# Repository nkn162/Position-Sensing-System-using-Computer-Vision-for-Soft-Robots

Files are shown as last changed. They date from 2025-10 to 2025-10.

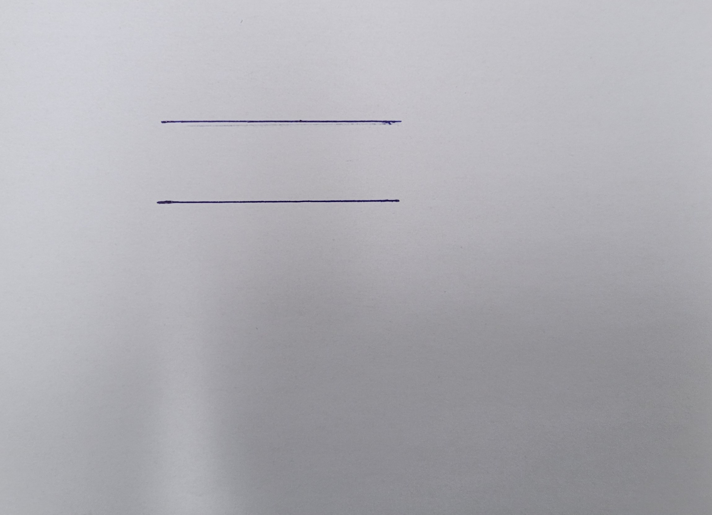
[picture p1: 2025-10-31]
Computer_Vision/Test_Inputs/image2.jpg

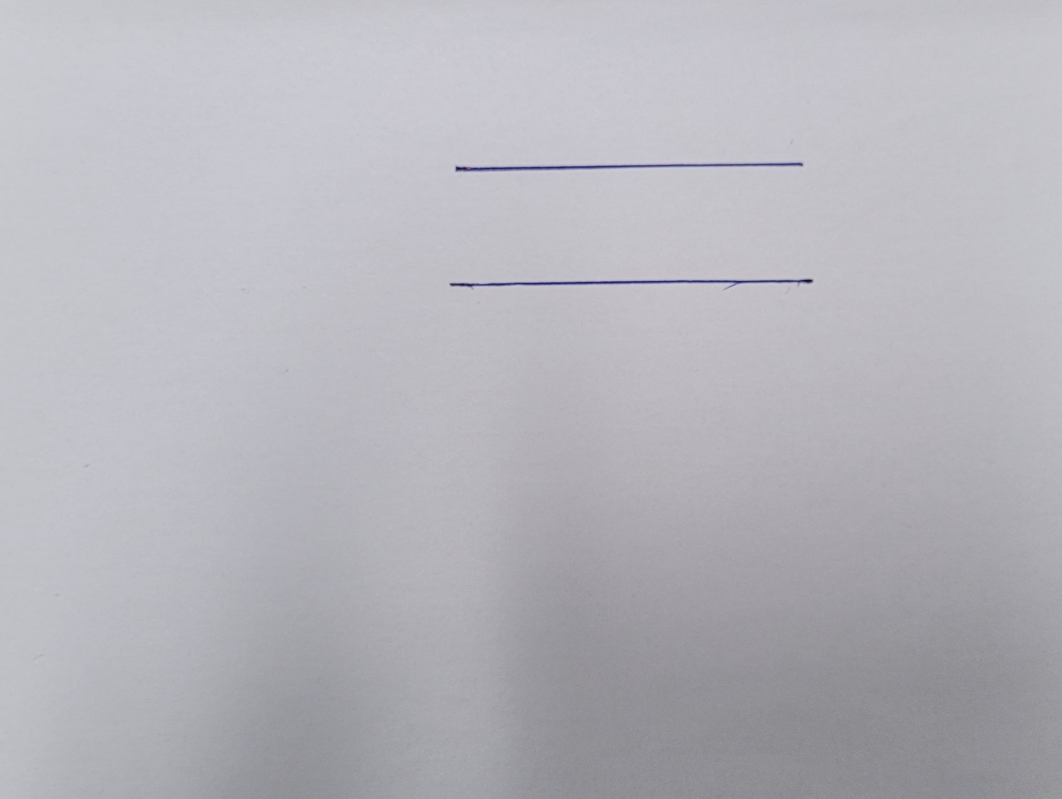
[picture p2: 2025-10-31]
Computer_Vision/Test_Inputs/image1.jpg

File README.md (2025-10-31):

# MRI-Safe Position Sensing for Soft Robotic Actuators via Computer Vision

## Master's Dissertation: A Novel Passive Sensing Approach for MIS

This Master's dissertation addresses a foundational challenge in future medical robotics: **accurate, flexible position sensing for soft actuators operating within the MRI environment.** Traditional sensing methods (EM/FBG sensors) introduce cost, complexity, or compromise the robot's essential compliance.

This project developed and validated a **novel, low-cost, and fully MRI-compatible passive mechanical sensing system** capable of inferring 3D tip position by tracking linear cable displacement using advanced Computer Vision techniques.

| Research Domain | Key Challenges Addressed | Core Technical Solution |
| :--- | :--- | :--- |
| **Computer Vision** | Real-time, sub-millimeter tracking of marked segments across low-contrast video streams. | Custom **Python/OpenCV** pipeline with temporal stability heuristics. |
| **Control & Kinematics** | Actuation control with NEMA 17 steppers; compensating for non-linearities and hysteresis inherent to soft actuators. | Calibrated **Constant Curvature Model (CCM)** firmware (Arduino). |
| **Medical Robotics** | MRI safety, preservation of soft actuator flexibility, low-cost disposal (single-use). | Passive cable displacement mechanism; non-metallic materials. |

---

## Contribution 1: Advanced Computer Vision Pipeline

The project implemented a sophisticated Computer Vision pipeline in **Python (OpenCV)**, optimised for real-time, accurate tracking of cable displacement at the actuator's proximal end.

### 1. Robust Detection & Filtering

The pipeline was engineered to reliably extract displacement data from high-noise, low-feature video frames - static images first before scaling towards video:
* **Pre-processing:** Utilised **CLAHE (Contrast Limited Adaptive Histogram Equalisation)** to locally enhance contrast, successfully resolving cable line visibility where simple global thresholding failed.
* **Feature Extraction:** Employed an adaptive **Canny Edge Detector** followed by a **Probabilistic Hough Transform** to parameterize the fragmented, near-horizontal cable lines.
* **Refinement:** Custom logic applied **Morphological Closing** to fuse broken segments and proximity-based merging to eliminate line duplicates resulting from cable thickness. *(See `Computer_Vision/edge_detection_5.py`)*

### 2. Temporal Tracking & Compensation

The system was scaled for dynamic video analysis, ensuring stability and compensation for physical artifacts during movement:
* **Stability:** **Persistence Logic** was implemented to reuse previous frame coordinates upon transient detection failure, ensuring a continuous and stable data stream at 30 FPS.
* **Motion Modeling:** To smooth inherent latency jumps in the raw coordinates, **Linear Interpolation** was applied to the displacement data between frames, accurately emulating the soft actuator's mechanical movement profile. *(See `Computer_Vision/Sensing_5.py`)*

---

## Contribution 2: Calibrated Kinematic Control Subsystem

To validate the sensing system, a controlled, cable-driven actuation platform was developed using an Arduino Due, integrating a corrected CCM (Constant Curavture Model) to handle the soft robot's mechanical non-linearities.

### 1. Actuator Control Firmware (`Actuator_Control/CCM_Trial_3.ino`)

The firmware implements the core kinematic logic for 3-DoF actuation via serial command (A, J, Z, R) on an **Arduino Due**:
* **Kinematics:** The **CCM** is used to calculate the necessary cable length change ($\Delta L$) for a target bending angle ($\psi$).
* **HMI:** Essential control commands (A: Absolute Move, J: Jog, Z: Zero Position) were implemented to facilitate manual compensation of mechanical slack and hysteresis during experimental resets.

### 2. Experimental Calibration and Correction

Physical trials revealed that the ideal CCM significantly overestimated bending. Analysis corrected the model for compliance, friction, and slack:
* **Correction Parameters:** Empirically derived parameters—**Actuation Efficiency ($\eta = 0.362$ scaling $\Delta L$)** and **Deadband ($\Delta L_0 = 3.04$ mm)**—were introduced and embedded in the firmware's logic to drastically improve prediction accuracy.
* **Hysteresis Analysis:** The experimental procedure included analysing hysteresis (measured up to $8.63^\circ$ at high deflection) and developing operational procedures (the 'Z' command) to mitigate its effect during validation runs.

---

## Contribution 3: Sensing Validation and Research Outcomes

The integrated system validated the viability of CV-based sensing, with quantified accuracy demonstrated through statistical modeling.

### 1. Non-Linear Mapping and Accuracy

* **Model Selection:** **Python regression analysis** was used to model the relationship between pixel displacement and bending angle. The **Quadratic Regression Model** was selected, yielding the lowest total error ($\text{RMSE} = 2.01^\circ$ across the full calibration set) due to its superior fit for the soft robot's intrinsic curvature. *(See `Calibration_Model/Correlation_Performance_2.py`)*
* **Final Accuracy:** The validated sensing system achieved high performance, with errors below **$\text{RMSE} = 0.81^\circ$** for typical surgical deflections ($> 15^\circ$).

### 2. Research Trajectory

This project establishes a strong foundation for advanced research by identifying the precise limitations and the pathway for a next-generation closed-loop control system:
* **Limitation:** Higher error observed at low angles ($\text{RMSE} \approx 3^\circ$), driven by minimal cable displacement visibility.
* **Proposed Solution:** The dissertation concludes that a design shift to **segmented PTFE tubes** would amplify displacement, directly addressing the low-angle sensitivity and paving the way for full-range high-accuracy position sensing. Furthermore, larger calibration data would provide a better fit for the correlation between measured displacement and bending angles. Trials using NDI Aurora Tracker, multi-camera environment, or evaluation against FBG sensors could validate the performance of the proposed sensing system more accurately and provide the pathway to further development of utilsing it for **closed-loop control integration**.

---

## Repository Structure

| Folder | Contents | Key Skills Highlighted |
| :--- | :--- | :--- |
| `Computer_Vision/Code_Files` | `edge_detection_5.py`, `Sensing_5.py` | **Python/OpenCV**, Image Processing (CLAHE, Canny), Temporal Tracking, Signal Processing. |
| `Computer_Vision/Code_Files` | `Correlation_Performance_2.py` | **Non-Linear Regression**, Data Analysis, Statistical Validation (RMSE). |
| `Control/` | `CCM_Trial_3.ino` | **Embedded C (Arduino)**, Stepper Motor Control, **Calibrated Kinematics**, HIL Prototyping. |
| `Output/` | Plots of calibration fit, residual analysis, and prototype schematics. | **Research Visualisation**. |

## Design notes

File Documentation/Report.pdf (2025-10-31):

## MRI Compatible Position Sensing for Soft Continuum Surgical Robots

MECH5845 Professional Project Author Name: Neeraj Krishnan Nambudiri
SID: 201887240
Supervisor Name: Dr. James Avery Examiner Name: Dr. George
Jackson-Mills
Date of Submission: 14/08/2025 MRI Compatible Position Sensing for Soft Continuum Surgical Robots

ii

SCHOOL OF MECHANICAL
ENGINEERING

MECH5840

TITLE OF PROJECT

PRESENTED BY

If The Project Is Industrially Linked Tick This Box And Provide Details Below

This project report presents my own work and does not contain any unacknowledged work from any other sources.

Signed | Date: 14/08/2025

Version 17, 2020-21

MECH5845M Professional Project

MRI Compatible Position Sensing for Soft Continuum Surgical Robots

Neeraj Krishnan Nambudiri

Company Name and Address:

INDUSTRIAL MENTOR:

iii

### Acknowledgements

I would like to express my deepest gratitude to my supervisor, Dr. James Avery, for

his continued guidance and support through the duration of this project. His advice

has been invaluable throughout the course and has made it possible for me to

achieve the project results.

I would also like to thank Sam Wilson for his guidance and cooperation in using the

lab space and equipment to conduct the project.

iv

### Table of Contents

v

vi

### Abstract

Minimally Invasive Surgery (MIS) increasingly employs soft continuum robots for their

dexterity, reduced-traumatic interaction, and ability to navigate complex anatomical

pathways. In procedures guided by Magnetic Resonance Imaging (MRI), sensing the

robot’s position is critical for accurate manipulation and safety. However, many

established tracking technologies face challenges of MRI incompatibility, size

constraints, or high cost.

This project presents the design and evaluation of an MRI-compatible, low-cost

sensing system for real-time curvature and tip position estimation in a cable-driven

soft continuum robot. The approach uses non-metallic tendons routed through PTFE

channels, with one end fixed at the robot tip and the other marked for visual detection

outside the MRI environment. A computer vision algorithm processes video frames to

track cable displacement, which is correlated to bending angle through calibration.

The development process included iterative refinement of image processing pipelines

from static to dynamic tracking, integration with a single-tendon cable-driven

actuation system based on the Constant Curvature Model (CCM), and calibration

using physical bending trials. Validation was conducted by comparing sensor-derived

angles with both manually measured angles and CCM predictions.

The system demonstrated reliable performance for moderate to large bends, meeting

real-time frame rate targets and maintaining MRI safety by keeping all sensing

electronics outside the scanner field. The results indicate that optical cable-

displacement tracking is a viable and scalable solution for MRI-guided continuum

robot sensing, with potential for integration into closed-loop surgical control systems.

vii

## Chapter 1

## Introduction

### 1.1 Background

Modern-day healthcare has been revolutionised by the introduction of Minimally

invasive surgery (MIS). It has enabled precision-driven procedures, aimed at

reducing patient trauma. In the applicable surgical domains, Robotic MIS has started

replacing open surgeries, due to its significant benefits such as greater patient safety,

faster recovery, lower post-operative problems, and reduced in-patient duration [1][2].

However, long and rigid instruments are used in traditional robot-assisted MIS, which

can have restrictions due to the fulcrum effect and some collateral damage to

surrounding tissue. This has resulted in prominent research developing soft robotics

for MIS, focused on combining rigid robotic control with flexibility and safety of soft

materials [2]. Figure 1.1 showcases the evolution of MIS and introduction of flexible

instruments in the field.

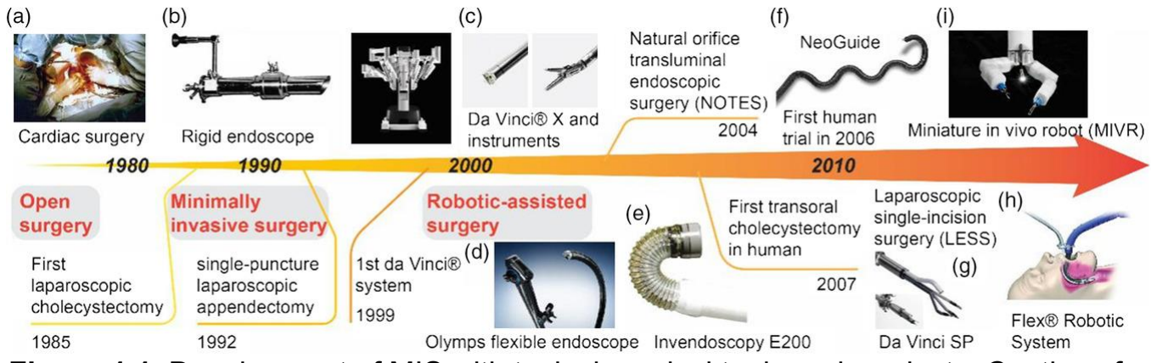
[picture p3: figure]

Figure 1.1: Development of MIS with typical surgical tools and products. Captions for individual images included within [3].

Simultaneously, the intervention of advanced imaging techniques, such as Computed

Tomography (CT), Ultrasound, X-ray, and Magnetic Resonance Imaging (MRI), with

MIS is also being developed. Among these, only MRI provides the data without any

ionising radiation. Hence, comprehensive study for integrating MRI during MIS

procedures is ongoing [4]. However, it poses considerable challenges due to the

presence of strong magnetic field, thus prohibiting the use of conventional metallic or

electrical sensing mechanisms for robotic control. Hence, development of alternative

proprioceptive sensing solutions is paramount. The most widely investigated sensing

technology is optical-based sensing, such as Fibre-Bragg Grating (FBG), fibre-scope,

and Fabry-Perot interferometer (FPI) [5]. They have exhibited high accuracy but also

have relatively higher stiffness which reduces the flexibility of the soft robotic manipulators and are very expensive, which limits their integration in single-use soft

surgical robots.

Accordingly, this project involves the design and evaluation of an MRI-compatible

sensing system tailored for the position tracking and motion control of a soft

continuum robot. It utilises a low-cost, flexible sensing system based on cable

transmission. The displacement of this cable, induced by robotic movement, is

captured using a camera setup and employing Computer Vision (CV) algorithm. It is

correlated to the bending angles for accurate position tracking, and its performance is

evaluated to analyse potential of offering a non-intrusive method for accurate motion

tracking without interference with MRI functionality. Figure 1.2 shows the reference

design of a soft-continuum robot.

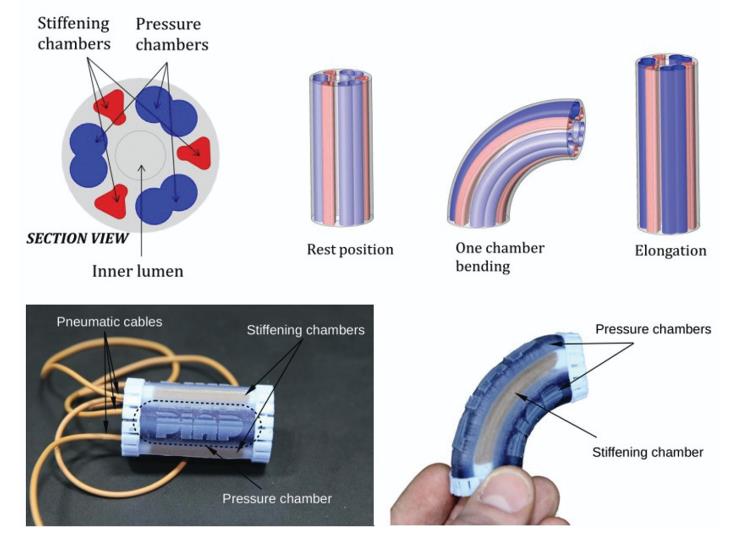
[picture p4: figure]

Figure 1.2: Example of a Soft Robot [6].

### 1.1 Project Aim

This project aims to develop and evaluate a size and stiffness tuneable, metal-free,

MRI-compatible sensing system for real-time position tracking of a soft continuum

surgical robot used in minimally invasive procedures.

### 1.2 Project Objectives

The key objectives to achieve the project aim are as follows:

1. Review relevant literature to understand the benefits and limitations of

existing technologies and finalise the methodology.

2. Design and implement the sensing system utilising Polytetrafluoroethylene

(PTFE) tubing and cable-displacement mechanism for motion tracking.

3. Integrate the sensor with the cable-driven continuum robot after preliminary

testing.

4. Develop a CV algorithm for detecting and quantifying edge displacement and

establish a robust correlation between detected cable-displacement and

robotic motion parameters.

5. Calibrate and perform validation to ensure system reliability, repeatability of

results, and account for hysteresis errors.

6. Assess accuracy, latency, speed, and precision of the proposed sensing

system.

7. Compare results with established sensing technologies such as Fiber-Bragg

Grating (FBG) and EM-tracker.

8. Target accuracy within 0.2 mm, delay of 0.1 seconds and frame rate of 30 fps.

### 1.3 Project Report Layout

- Chapter 1 – Introduction: Establishes the background of the project and

specifies the corresponding aims and objectives.

- Chapter 2 – Literature Review: Provides a critical review of relevant literature

for all aspects of the project, from MRI-guided MIS to Fabrication methods.

- Chapters 3 to 5 – Project Development: Describes in detail the methodologies

of all the aspects – CV system, Fabrication, and Actuation Control.

- Chapter 6 – Validation Experiment: Describes the experimental setup and

methodology for evaluation of the sensing system, along with the results and

analysis of its performance.

- Chapter 7 – Conclusion: Summarises the key achievements, results,

discusses significance and limitations of the findings, and outlines potential

pathways for future work.

## Chapter 2

## Literature Review

### 2.1 Introduction

The convergence of soft robotics and MRI-guided intervention in MIS procedures

have amplified the need for developing robust, accurate, and reliable soft sensing

technologies and unveils a new, critical frontier in the field of medical robotics

research. They are capable of navigating complex anatomical structures, providing

additional dexterity and accessibility [7]. The robotic systems also elevate the skills of

a surgeon, while delivering higher precision and accuracy [8]. At the same time, it

also presents interdisciplinary challenges, due to the multiple constraints – clinical

and technical. To overcome these challenges, adaptation and re-imagining of the

feedback mechanisms for robot position is required. This literature review will explore

the current benchmarks in the domain. Furthermore, validation of the proposed

sensing system requires the development of a working prototype of the soft

continuum robot, which is also discussed briefly.

### 2.2 MRI Guidance in Minimally Invasive Surgery

MRI stands as the benchmark for soft tissue visualisation and hence adds

considerable value when used as guiding intervention for MIS procedures. It offers

unparalleled contrast resolution, continuous and real-time monitoring without any

cumulative radiation exposure – critical for patient safety. But it also necessitates

specific surgical instrumentation, based on the constraints exemplified due to the

presence of strong magnetic fields in these environments.

2.2.1 Regulations for MRI Compatibility

The electromagnetic compatibility of components and devices used in a surgical

procedure are critical in an MRI environment. Based on their safety in MRI

environment, the American Society for Testing and Materials (ASTM) F2503 [9]

categorises the systems into three: MR Safe, MR Conditional, and MR Unsafe. MR

Safe devices are neither affected nor influence the magnetic field in an MRI

environment. These instruments are made of non-metallic, non-conductive, and non-

magnetic materials. MR Conditional stipulates instruments which are demonstrated

to be safe in an MRI environment, but only under specific conditions. MR Unsafe

devices are classified as hazardous for functioning in an MRI environment [9].

Based on this classification by ASTM, this project aims at developing the sensing

system which would be MR Safe, thus highlighting its application in all MRI

environments, without accommodating any specific criteria. This would be ensured

by selecting metal-free and non-conductive materials in the region of the surgical

procedure.

2.2.2 Technical Challenges for MRI-guided MIS

The strong magnetic field, radio frequency pulses, and gradient coils of the MRI

machine interfere with the operation of traditional robotic systems. At the same time,

the metallic components in the robots can distort the quality of the MRI data [4] [10],

thus reducing the efficacy of the procedure. This inherent incompatibility lays the

foundation of most technical challenges associated with MRI-guided MIS procedures.

In developing solutions for these, MR Safe or MR Conditional robotic systems have

been designed, utilising non-magnetic and low-susceptible materials [4].

Among these design research, optical and EM based sensing technologies were the

most widely explored. However, other sensing modalities require further

investigation.

Parallelly, a lot of development has also occurred in design of soft robots. The

primary advantages, when compared to rigid systems, are crystal-clear – offering

higher manoeuvrability while decreasing possibility of patient trauma during surgical

procedures [11]. However, these properties also lend to greater complications in

integrating sensor modalities – since conventional sensors are mostly made of rigid

components [12] [4].

This highlights the critical need of developing a reliable, MRI-compatible sensing

technology which is capable of providing real-time position sensing to propel further

applications of MRI-guided surgery.

### 2.3 Contemporary Sensing Technologies

2.3.1 Optical Sensing Methods

Through the growing research in MRI-compatible sensing modalities, optical systems

have emerged as the pre-eminent solution, capitalising on their fundamental

immunity to electromagnetic interference. Figure 2.1 showcases the general array of

sensing technologies.

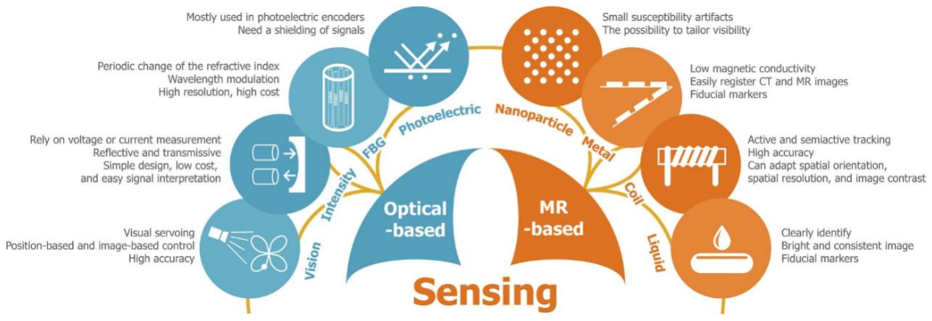
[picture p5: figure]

Figure 3.1: Contemporary MRI conditional/safe sensing methods [4].

For instance, Su et al. [13] demonstrated the development of an MRI-compatible soft

robotic system that would be used in neurosurgical procedures and utilized fibre optic

sensors to determine the position and force applied at the robot tip. The research by

Fang et al. [14] indicates the development of a soft robotic gripper and uses an

optical waveguide to transmit laser in transoral laser ablation. A fiberscope is

integrated within the soft actuator allows the position-tracking by following the laser

and provides closed-loop control during operation. The design in shown in Figure 3.2.

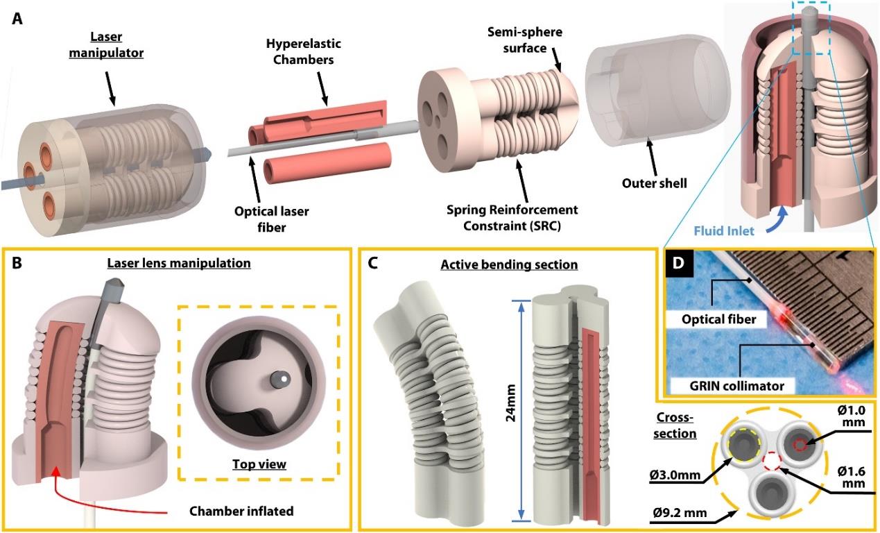
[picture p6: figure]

Figure 3.2: Design of Soft Robotic Laser Steering System [14].

It has shown very good accuracy (approx. 0.2 mm) during various in-vitro and animal

trials. However, due to the need of specialised fiberscope for the position tracking,

the compactness is affected, reducing flexibility when compared to other soft surgical

tools. This constraint can be crucial in evaluating the viability of the technology for

MRI-guided surgeries, since the space within the MRI bore is a critical limiting factor

for design requirements. The reduced miniaturising property due to the optical

fiberscope can pose challenges in surgical applications for certain anatomical

regions.

Fibre-Bragg Grating (FBG) technology is currently considered as the gold-standard

for MRI-compatible sensing, due to its highly accurate and reliable performance. The

principle of the sensor involves periodic refractive index variations within the fibre

core that reflect specific wavelengths proportional to local mechanical strain,

visualised in Figure 3.3. This distributed sensing modality allows accurate

quantification of the shape of the robot and tip-position [13].

While the core technical performance is very good for FBG sensors, they often

demonstrate non-linear and hysteretic behaviour. Furthermore, the requirement of

highly sophisticated equipment for wavelength measurements and spectral analysis

increases the cost of these systems drastically, making it difficult to integrate with

one-time use soft surgical tools currently in development.

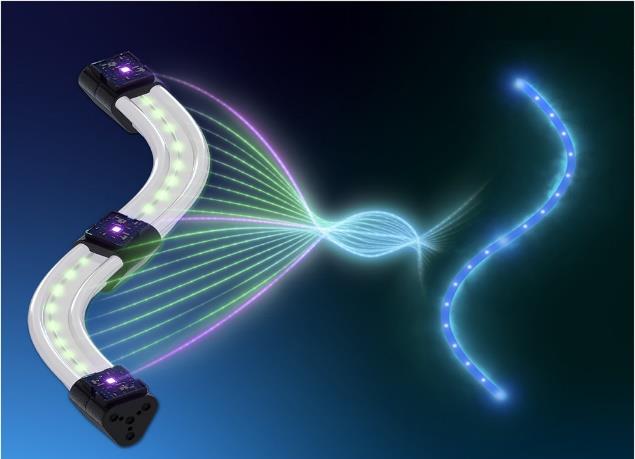
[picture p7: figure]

Figure 3.3: FBG Sensing principle visualisation [15].

Fabry-Perot Interferometric (FPI) sensors utilise phase-modulation principle to

achieve high sensitivity in compact soft surgical tools. These have shown exceptional

performance in force-sensing applications [16]. But, similar to FBG sensors, these

are also limited by the need of extremely expensive equipment for completing the

sensing framework.

2.3.2 MR-Based Sensing and Other Modalities

The utilisation of MRI signals directly for sensing, provide an elegant alternative by

leveraging the in-use imaging equipment.

There are Active Tracking Systems, which have shown impressive performance

capabilities. They employ active coil to amplify the existing electromagnetic field, to produce high contrast images allowing real-time tracking [17]. But, the presence of

another magnetic field within the environment has shown potential in degradation of

the image quality, which can force trade-off between tracking accuracy and imaging

quality.

Passive Marker Techniques addresses these quality concerns by employing MR-

conditional materials [17]. But these require specialised hardware and setup, careful

optimisation of size, shape, and material properties to minimise the degradation while

maintaining adequate contrast for precise tracking.

EM Tracker employs a transmitter for a separate electromagnetic field, which is

sensed to locate the position of the robot [12]. But this requires specialised hardware

and minute calibration to avoid interference with the MRI magnetic field, to be termed

MR-Safe. The setup is shown in Figure 3.4.

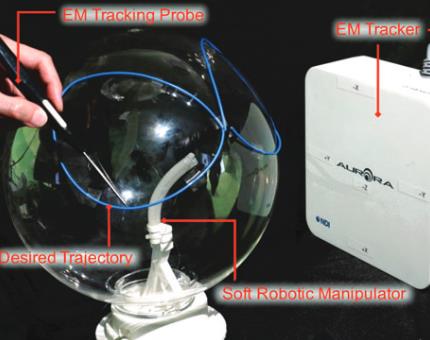
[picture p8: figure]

Figure 3.4: EM Tracker [18].

There are other sensing methodologies which are emerging with promising results.

Lin et al. [19] demonstrates a proprioceptive sensing method for an elastomeric

finger. It employs a combination of fibre-based displacement sensors and microfluidic

pressure sensors, as shown in Figure 3.5. The fibre-based sensors measure bend,

twist, and elongation, while the microfluidic sensors measure overall and local

pressures. These are passive sensors, transmitting information optically to a camera

for recording [19]. This approach reduces the computational resource demand while

preserving higher accuracy and flexibility.

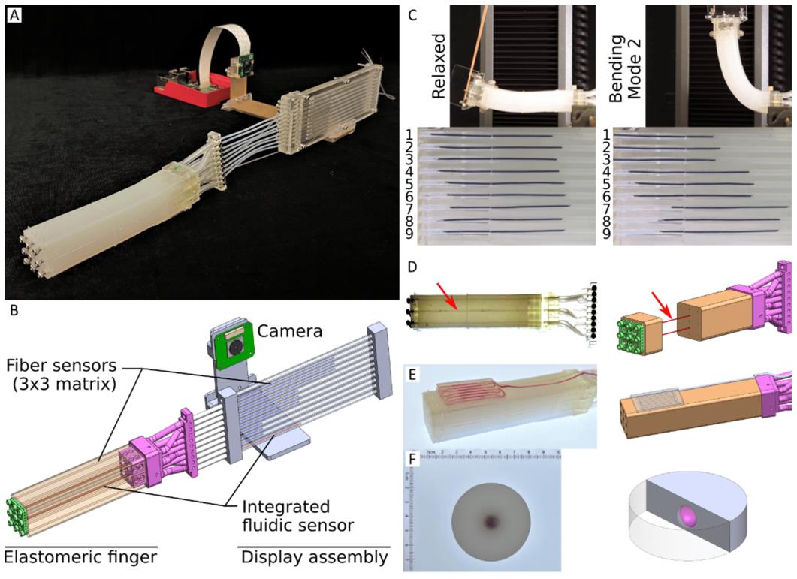
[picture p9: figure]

Figure 3.5: Fibre-based and Microfluid Soft Sensors. A) Elastomeric finger with the

sensors. B) Illustration of sensors through the elastomeric finger. C) Fiber-based

sensor. D) Microfluid sensor. E) Surface-mount pressure sensor. F) Colour cell

pressure sensor [19].

The above principle opens-up the possibility of utilising fibre-displacement sensing

principle as a promising alternative to existing sensing systems which were

compared earlier. The limited scalability and cost constraints of optical systems are

improved with this principle, while having no interference with the MRI magnetic field

like the MR-based sensors.

### 2.4 Kinematic Modelling for Soft Robot Actuation

Soft continuum robotic systems distinguish themselves from traditional rigid-link

robots by operating without conventional revolute or prismatic joints. Instead, their

movement is based on continuous deformations in shape, often inspired by biological

actuators. These robots are typically actuated by hydraulic, cable-driven or

pneumatic systems.

- Pneumatic Actuators: These are the most common actuation method for MRI-

compatible robots. They operate by inflating or deflating hollow chambers

within the soft material structure, leading to bending or elongation [20].

- Hydraulic Actuators: These systems use liquid flow to actuate the robot,

offering advantages like intrinsic MR safety and the ability to miniaturise the

robot's design by placing larger actuator systems outside the MRI room [10].

- Tendon-Driven (Cable-Driven) Systems: These involve pulling cables guided

within channels along the manipulator fixed at its tip, enabling bending [10].

Within the framework of the MRI-compatible soft robot, hydraulic actuation would be

the best method, since it need not employ any metallic or magnetic materials. But

they are difficult to fabricate and integrate mechanically. The primary scope of this

project is to develop the sensing system and validate its performance. The actuation

is only incidental for the prototype development – since the sensing system is

completely independent of the actuation methods. To facilitate the project with those

considerations, cable-driven actuation would be employed for this project, with the

analysis that if the sensing system is validated, it can be later integrated with MRI-

safe actuation methods like hydraulic actuation for future in-vitro trials.

2.4.1 Kinematic Modelling

The inherent compliance and continuous deformations of soft continuum robots,

coupled with their theoretically infinite degrees of freedom, make their modelling and

control notoriously difficult.

Constant Curvature Model (CCM): It is a widely applied simplified kinematic model

for continuum robots. It approximates the robot's curvature remains constant. It is

computationally efficient and has been widely used for both single-section and multi-

section manipulators [21] [22].

- Errors and Approximations: Despite its utility, the CC model is an

approximation and does not completely match all characteristics of continuum

robots, particularly in accurately reflecting complex deformations or the

influence of external forces.

Variable Curvature Models To achieve greater accuracy, especially when considering

external forces and positional constraints, variable curvature modelling methods have

been developed, like Lagrangian polynomial series. These models move beyond the

constant arc approximation to describe more complex deformations [21]. However,

they add much higher computational difficulties, which would prove beyond the scope

of this project. Hence, CCM would be employed as the basis for actuation during

validation trials, accounting for the inherent errors and approximations by correction

factors and repeated trials for empirical data.

## Chapter 3

## Computer Vision Sensing System

### 3.1 Introduction

In the context of MRI-compatible soft continuum robots, position sensing must be

accurate, minimally intrusive, and non-disruptive to the robot’s mechanical

compliance. Computer Vision (CV) offers an alternative method of tracking

deformation through visual markers, while being remote from the actuating system

[23].

This work develops a CV-based sensing pipeline tailored to a cable–PTFE tube

mechanism integrated into the robot. The concept involves tracking pre-marked

cables at the distal ends of PTFE tubes, far outside the MRI environment to a static

camera, shown in Figure 3.1. Cable displacement, induced by robot bending, is

captured using a camera. CV is applied to compute this displacement, and it is

correlated to the bending angles for calibration.

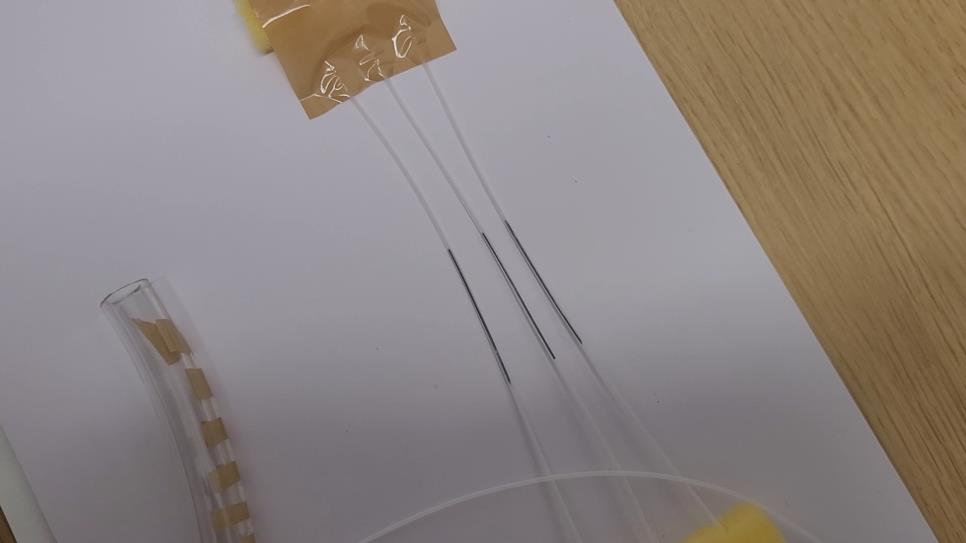
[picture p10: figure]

Figure 3.1: Basic setup of the marked cables used for position sensing

The methodology was implemented entirely in Python with OpenCV and progressed

through an iterative development cycle:

1. Baseline Algorithm – Static Image Processing
2. Extension to video processing from camera using temporal tracking
3. Calibration - Correlating of displacement to bending angle by performing standard angular movements manually

4. Evaluation of model accuracy and limitations

### 3.2 Static Image Processing – Algorithm Prototyping

Initial trials focused on static images of two high-contrast horizontal lines

(representing the marked cables) on a white background. This controlled

environment allowed methodical testing of detection strategies before extending to

physical cable image captures.

3.2.1 Methodology

The static image pipeline (refer to Appendix 1 for code) consisted of:

- Preprocessing: Conversion to grayscale to reduce data dimensionality and

simplify intensity-based operations.

- Contrast Enhancement: Application of Contrast Limited Adaptive Histogram

Equalization (CLAHE) to amplify line (representing the marked cables)

intensity while avoiding oversaturation of bright regions, shown in Figure 3.2.

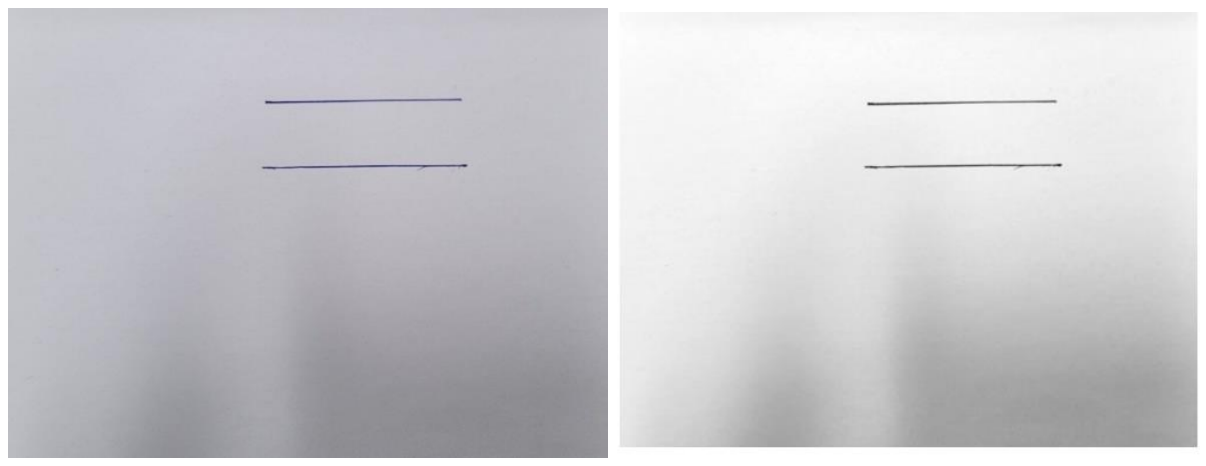
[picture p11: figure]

Figure 3.2: Image Processing Flow (a) Original Image. (b) Contrast Enhancement.

- Edge Detection: Canny edge detection with tuneable thresholds. Modified

from fixed thresholds early on to adaptive thresholds for better performance.

- Line Detection: Probabilistic Hough Transform to parameterise detected

edges into discrete line segments, with filtering for near-horizontality – since

the marked cables would always be horizontal based on the controlled

environment of image capture in the eventual sensing system, shown in

Figure 3.3 (a).

- Post-Processing: Morphological closing to connect fragmented edges and

merging logic to combine segments belonging to the same line, shown in

Figure 3.3 (b).

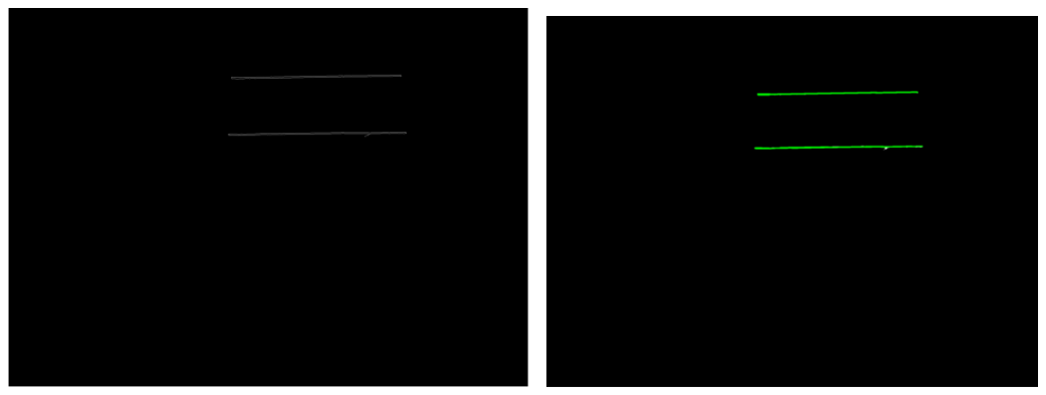
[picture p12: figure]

Figure 3.3: Image Processing Flow - 2 (a) Line Detection. (b) Post-processing.

3.2.1 Observations and Refinement

Initial outputs successfully detected the target lines but presented two consistent

challenges:

- Line Fragmentation: Multiple short segments per cable were detected.

Tuning the thresholds for maximum distances between possible lines and

applying morphological closing improved continuity.

- Duplicate Detection from Line Thickness: Single drawn lines were

detected as multiple ones due to their thickness. This was mitigated through

proximity-based merging, discarding duplicates based on the y-coordinates.

By the final static iteration, the algorithm consistently identified the two target lines

with minimal false positives. Remaining duplicates were tolerated at this stage, with

merging deferred to the video processing stage.

### 3.3 Video Processing – Dynamic Line Tracking

This algorithm was scaled for dynamic tracking to enable video processing and real-

time coordinate extraction under movement. The camera captures video at 30 fps,

which was included as a factor in the pipeline by handling frame-to-frame variability

and motion blur.

3.3.1 Methodology

The dynamic pipeline (refer to Appendix 2 for code) incorporated several extensions

to the static image processing logic:

1. Frame Acquisition and Storage: Videos were processed frame-by-frame,

with intermediate outputs (grayscale, contrast-enhanced, edges, lines) for

debugging and parameter tuning. Figure 3.4 shows a frame from the

intermediate output of first trial, indicating false detection of edges of the

PTFE tubes, highlighting need for higher contrast and pre-processing

thresholds.

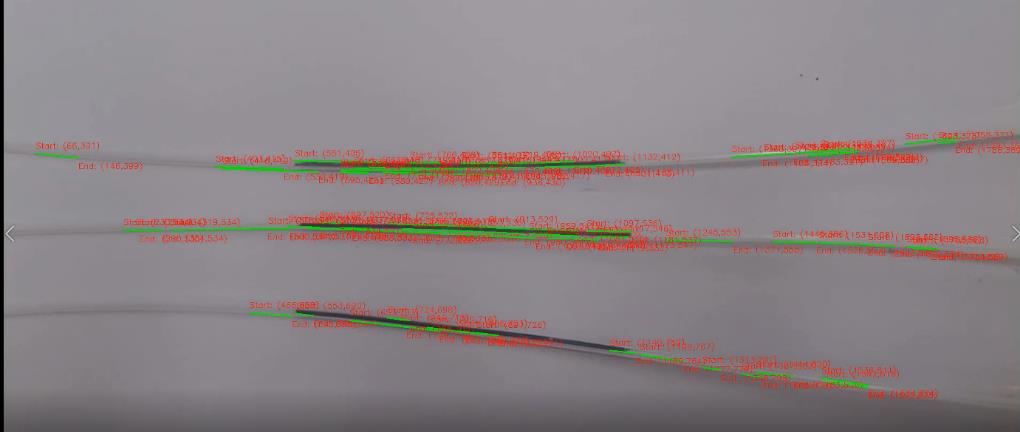
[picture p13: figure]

Figure 3.4: Output frame of 1st trial – multiple lines detected and frame edges

2. Region of Interest (ROI) Masking: With the static camera and assurance of

controlled environment, the focus of processing and computation was limited

to the central region containing the cables, thus reducing false positives from

frame edges.

3. Persistence: If a band failed to detect a line in a given frame, the previous

frame’s coordinates were reused (persistence), preventing data gaps. Figure

3.5 shows a frame with missing segments.

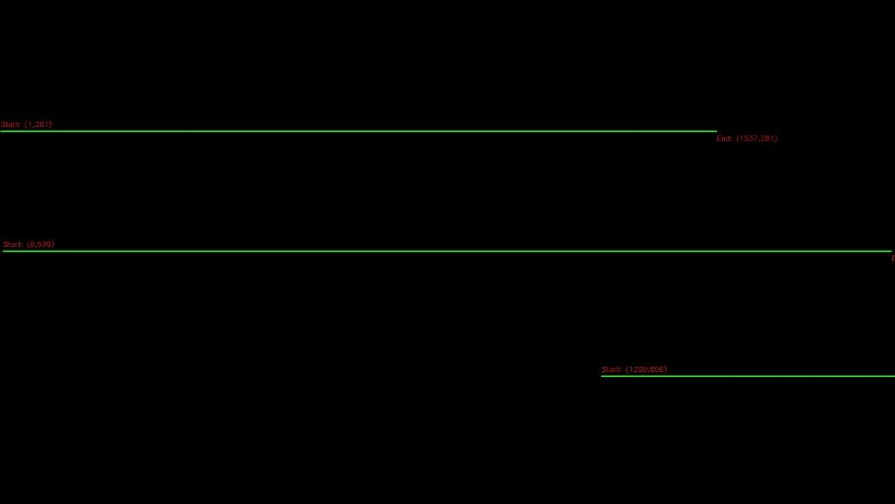
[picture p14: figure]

Figure 3.5: Frame of output video with missing segments

4. Gradual Motion Modelling: When the marked cable moves, at certain points

sudden jumps in the coordinates were observed due to latency. The

datapoints between frames were interpolated linearly to emulate gradual

bending, matching the mechanical actuation profile.

Flowchart for final logic is shown in Figure 3.6.

Figure 3.6: Flowchart of entire video processing pipeline

3.3.2 Observations and Refinement

The final video processing stage output clean, temporally consistent tracks of the

three cable lines, with overlaid coordinates for each frame. Figure 3.7 shows 3

frames from the output video – showcasing the processed output with a moving

cable.

Figure 3.7: Frames of final output video (a) First frame. (b) Intermittent frame with 1

marked cable moving. (c) Final frame when cable back to initial position.

### 3.4 Displacement-Angle Correlation and Calibration

With dynamic coordinates extracted, the horizontal displacement from its baseline x-

position was used as the primary sensing signal. The correlation (refer to Appendix 3

for code) mapped displacement to bending angle.

3.4.1 Data Collection

Trials were conducted with the robot manually bent to known angles on a plane (30°,

45°, 90°, 120°, 135°) in both left and right directions. Displacements (measured in pixels – px) ranged from 15 px (30°) to 41 px (135°). Inside and outside cables (3rd

cable would remain stationary when bending the actuator on a plane, based on the

placement configuration) showed equal magnitude but opposite sign shifts (±1 px

variability), validating the symmetry assumption.

3.4.2 Model Fitting

Three geometric models were fitted and evaluated, shown in Figure 3.8 and Figure

3.9:

- Linear: RMSE ≈ 7–10°, insufficient for nonlinear curvature
- Quadratic: RMSE = 2.01°, best overall fit
- Sine: RMSE ≈ 9°, underperformed without offset correction

Residual plots indicated the quadratic fit captured the curvature of the displacement–

angle relationship, particularly in the calibrated range (30°–135°), with <3° residuals

for 80% of points. RMSE comparison for each fit is shown in Figure 3.10.

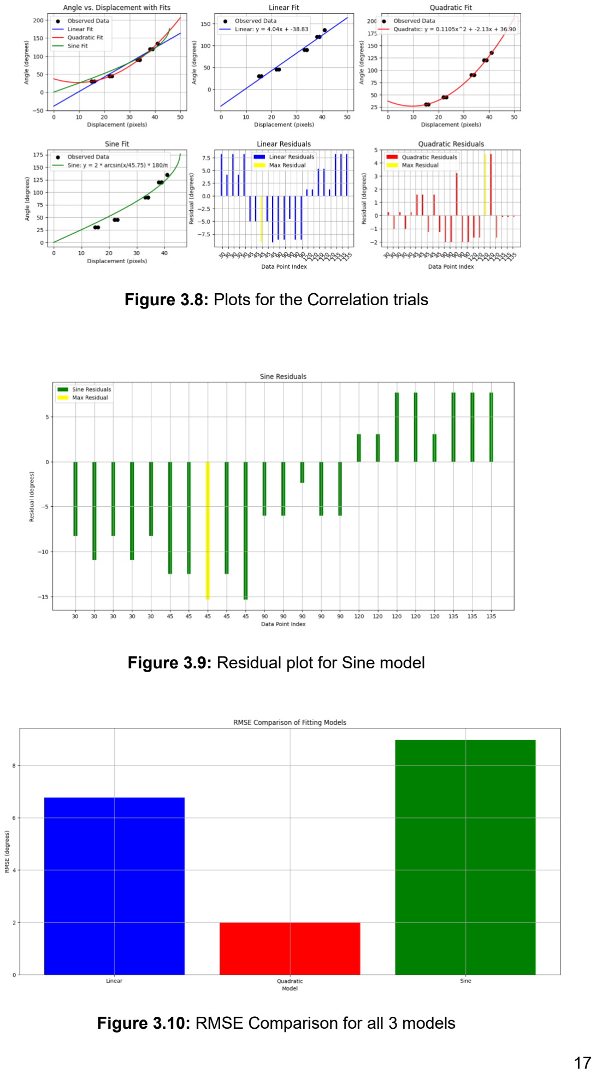
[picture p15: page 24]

Figure 3.8: Plots for the Correlation trials

Figure 3.9: Residual plot for Sine model

Figure 3.10: RMSE Comparison for all 3 models

### 3.4 Discussion

The implemented CV-based sensing system successfully demonstrated the feasibility

of translating cable displacement into bend-angle measurements for a soft continuum

robot. The quadratic displacement–angle mapping achieved an RMSE of 2.01°

across 23 calibration points, which is competitive with, and in some cases superior

to, other non-contact approaches for soft robotic kinematic estimation. For context,

strain gauge implementations in comparable compliant systems typically report

angular errors of 3–5°, while fibre optic shape sensing can achieve sub-degree

accuracy but at significantly higher cost, complexity, and with potential MRI

compatibility concerns.

An important observation from the empirical data is that displacement increases

nonlinearly with bending angle, which aligns with the constant curvature assumption:

the arc length change in a cable positioned radially at distance r from the neutral axis

is proportional to rθ for small angles, but deviations appear at larger deflections due

to material compliance, sheath friction, and geometric constraints. The quadratic

coefficient (α=0.1105) effectively captures the accelerating rate of displacement

growth at high curvature. However, due to limited data points at low angles (< 25°),

the quadratic fit in the region is not robust. This can be attributed to Signal-to-noise

limitations – at small bends, pixel-level displacement is minimal (≤10 px), making

measurements more sensitive to camera resolution, edge localisation error, and

optical distortions. This could be improved by changing the image capture

perspective, higher resolution may allow higher displacement (in terms of px) even

for lower angular movements of the robot. Employing hybrid fitting models may also

help in the distinct behaviours at different regions.

Interestingly, the theoretically superior sine model—under ideal constant curvature

geometry and perfect projection—underperformed compared to quadratic fit (RMSE

~9° vs. 2.01°). This suggests that mechanical factors such as friction, non-planar

bending (miniscule twisting during trials), and camera perspective distortion break the

ideal geometric mapping, reinforcing the need for data-driven calibration.

Another engineering confirmation is directional symmetry. Left and right bends

exhibited nearly identical displacement magnitudes (±1 px variance). Hence,

magnitude-only calibration was carried forward. For higher accuracy iterations,

especially when incorporating closed-loop system, signed displacement model with

separate coefficients can be utilised for the minimal asymmetries.

## Chapter 4

## Fabrication

### 4.1 Introduction

The fabrication aspect was intended to provide a suitable physical platform for the

testing and validation of the MRI-compatible sensing system. While the primary

research focus was the sensing methodology, an appropriate soft actuator was

required for calibration and testing. The initial plan involved designing and

manufacturing a custom silicone soft robotic segment according to defined surgical

and mechanical constraints. However, due to manufacturing challenges, timeline

constraints and the availability of an existing actuator matching the key

specifications, a previously fabricated soft robot was adopted for the experimental

phase. Nevertheless, significant design work was undertaken in preparing the mould

and ancillary hardware, and the complete sensing hardware assembly was

integrated.

### 4.2 Actuator Design Requirements

The target actuator was specified as a cylindrical segment of approximately 10 cm

length, with:

- Six peripheral channels (1.1 mm diameter) positioned equidistantly, located

midway between the central axis and the outer wall.

- One central channel to accommodate a surgical instrument such as an

endoscope.

- An overall diameter less than 2.0–2.5 cm to conform to minimally invasive

surgery (MIS) port constraints.

These requirements were driven by both the needs of a cable-driven actuation

system and the dimensional limitations of MIS procedures.

### 4.3 Mould Development and Iterations

All designs were modelled in SolidWorks. The first mould concept was designed to

be longitudinally split, two-part assembly with a 3 cm outer radius, shown in Figure

4.1. This was reduced to 1.5 cm radius after review to comply with MIS framework

constraints.

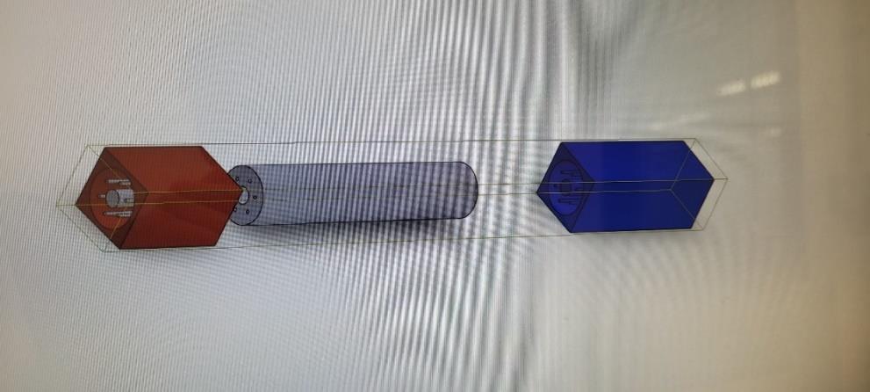
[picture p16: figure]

Figure 4.1: First design for Soft Robot Fabrication Mould

To minimise the risk of tearing the cured silicone during demoulding, the split line

was reoriented from a longitudinal to a transverse arrangement, allowing vertical

separation of the mould halves. Another design iteration, shown in Figure 4.2 was

done to include the addition of vent holes to improve silicone curing and degassing,

which was missed in the first 3D-printed iteration.

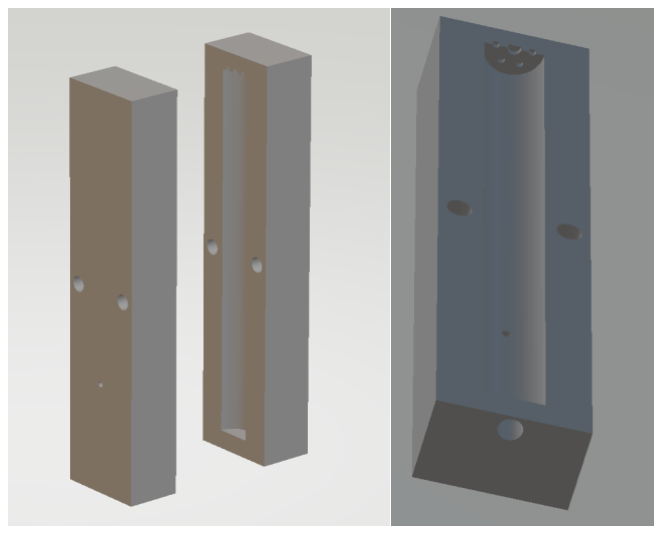
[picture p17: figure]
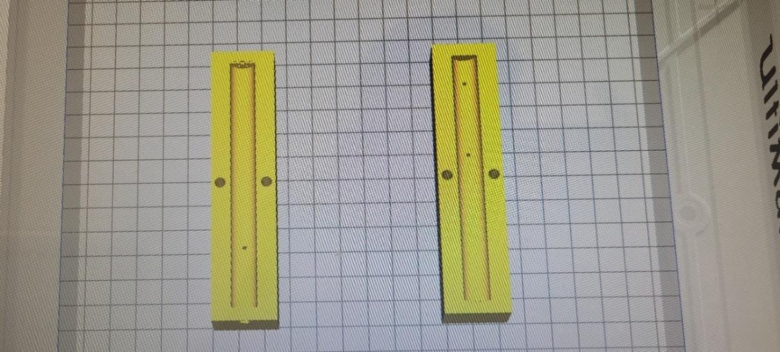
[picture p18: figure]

Figure 4.2: Updated Design for Mould – (a) Isometric view. (b) Lateral view for slots

for channel creation. (c) 3D printer (Ultimaker) view

Channel formation was planned by inserting stainless steel rods (1.1 mm diameter,

10.5 cm length) into predefined slots within the mould, corresponding to the cable

and central lumens. The rods were fabricated in-house in the mechanical workshop,

shown in Figure 4.3 and were to be withdrawn post-curing, leaving clean channels for

PTFE tube insertion. A dedicated endcap was also 3D-printed with anchoring slots

for actuation and sensing cables and a central aperture for instrument passage.

Figure 4.3: Fabricated metal rods for channels

### 4.4 Adoption of Existing Actuator

Despite several completed design iterations, manufacturing challenges and the risk

of further delays led to a change in approach. An existing soft robotic actuator — in

prior fabrication by the departmental lab (under Dr. James Chandler) — was

evaluated. It had near-identical specifications: 11.6 cm length, 1.7 cm diameter, six

1.2 mm peripheral channels, and a central channel. This close alignment with the

requirements, this actuator was adopted for the remainder of the work, shown in

Figure 4.4. This allowed project effort to be refocused on the sensing system

integration, calibration, and validation, consistent with the primary objectives.

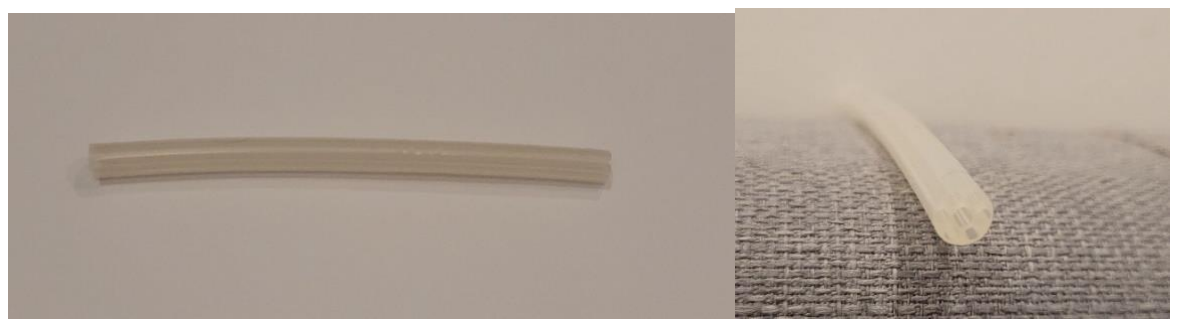
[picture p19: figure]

Figure 4.4: Side and Front view of Actuator

### 4.4 Ancillary Hardware – Spool Design

The stepper motor spool for cable actuation was designed and fabricated. Initially,

adhesive bonding of the cable end to the spool flange was planned; however,

maintaining tension proved problematic, and cables slipping was observed. The

spool was subsequently redesigned with a through-hole in the flange, thus allowing the cable to be tied securely, shown in Figure 4.5. This proved robust under repeated

actuation. Additional features such as circumferential grooves could have further

reduced slippage and improved cable winding consistency, but the final design was

retained for simplicity and reliability during validation.

Figure 4.5: Spool Design

### 4.6 Summary

While the actuator fabrication process was eventually bypassed in favour of an

existing one, the design phase demonstrated iterative refinement, manufacturability

considerations, and risk mitigation. The sensing system hardware, including PTFE

tube routing, cable anchoring, and camera alignment, was fully assembled and

integrated with the adopted actuator to form the experimental platform.

## Chapter 5

## Actuation Control – Constant Curvature Model

### 5.1 Introduction

The actuation subsystem was developed to enable controlled bending of the soft

continuum robot for sensing system validation. The Constant Curvature Model (CCM)

was selected as the framework for kinematic modelling due to its widespread use in

continuum robot control and computational simplicity.

The implementation was done initially by simulating the algorithm to verify its

performance – first for 1 DoF bending and then extended to 3D space. This approach

allowed systematic testing of cable-driven CCM actuation principles. During

mechanical implementation, the approximations and deviations from ideal model

predictions were identified, and corrective calibration parameters were developed.

### 5.2 The Constant Curvature Model

The CCM approximates a continuum section of length L as an arc of a circle with

curvature κ and bending plane orientation ∅. For a single tendon at radial offset r

from the neutral axis and angular position θc

, the change in tendon length ∆L is given

by [22]:
∆L = −κr ∙ cos (θc − ∅) ∙ L | (5.1)

where: ∆L = change in tendon length; κ = curvature (1/radius) r = radial cable offset;

θc = cable angular position in cross-section; L = section length

Under ideal conditions (no frictional losses, perfect tension, rigid cable path

geometry) it provides a one-to-one mapping between calculated cable displacement

and resulting robot curvature.

### 5.3 MATLAB Simulation

A MATLAB environment was developed to:

1. Generate tip coordinates for varying curvature κ and bending plane ∅.
2. Calculate cable length changes for a given target bend.
3. Visualise robot bending in real time using user inputs.
4. Log actuation parameters including cable pulls, motor step counts, and

corresponding tip positions.

This simulation, whose results are shown in Figures 5.1 and 5.2, provided an

idealised baseline for physical tests, enabling direct comparison between predicted

and measured behaviour.

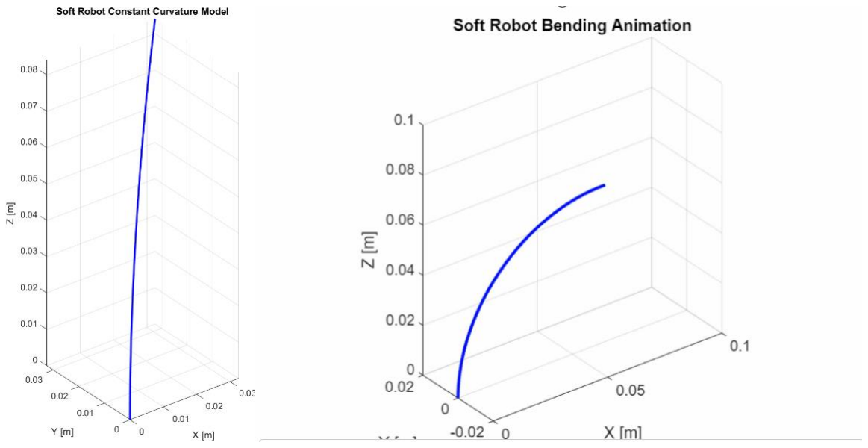
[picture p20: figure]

Figure 5.1: Simulation Visualisation in MATLAB

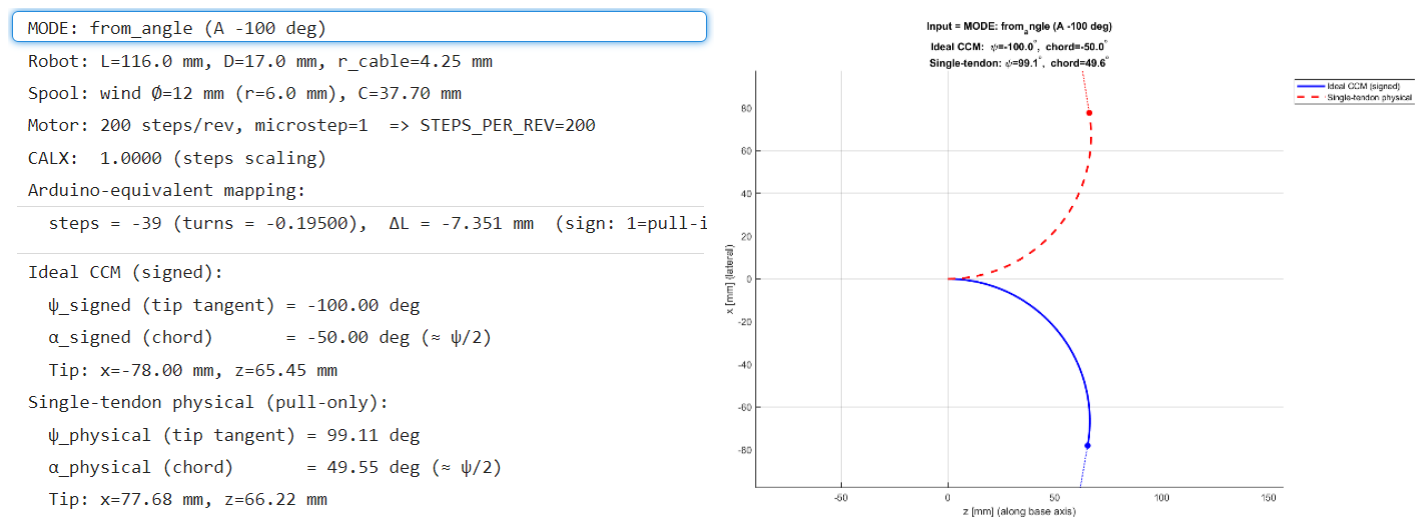
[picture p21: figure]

Figure 5.2: Inverse Kinematics Output to calculate motor steps and cable length

### 5.4 Hardware Implementation

The adopted soft actuator, as highlighted in Chapter 4, was integrated with the

electro-mechanical setup for the actuation, shown in Figure 5.4. The components

were as follows:

Actuation System

- Motors: NEMA 17 stepper motors (×3)
- Drivers: DRV8825 micro-stepping drivers (×3)
- Controller: Arduino Due with Protoneer CNC Shield V3.00
- Cables: 0.5 mm fishing line (non-metallic for MRI compatibility)
- Spools: Custom-designed, as specified in Chapter 4

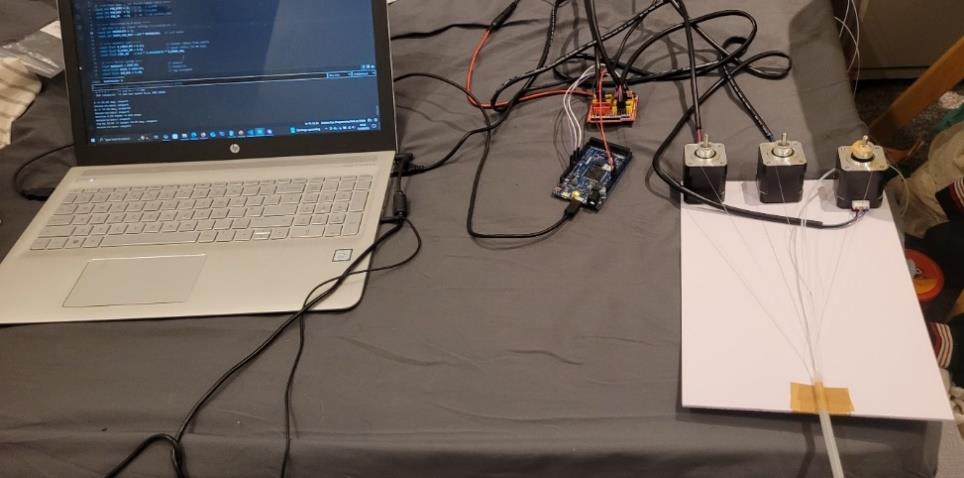
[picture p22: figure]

Figure 5.3: Hardware setup for Actuation Trails

5.4.1 Arduino Firmware Development

The control firmware was designed for serial command-based operation (refer to

Appendix 4 for code). Provisions were added for user-inputs for controlling the

actuation in real-time, simulating commands during surgical procedure:

- A → Move to absolute motor angle
- J → Jog relative to current position
- Z → Set current position as zero (critical for re-tensioning after slack)
- SPD → Set maximum speed
- REV → Rotate motor a set number of turns (micro-stepping verification)
- H → Oscillate between ±target angle (for demonstration/testing)

The Z command was particularly important for compensating mechanical slack and

hysteresis by allowing manual re-zeroing without power cycling.

### 5.5 Experimental Procedure

Step 1 – Motor-Only Verification
- Verified command execution without robot attached
- Checked correlation between commanded steps and angular displacement
Step 2 – Robot Integration
- Robot and motor mounted to common baseplate to eliminate unwanted

translation

- Tendon routed through channel and tied to spool
- Initially tested with micro-stepping = 16. Then switched to full-step to improve

control resolution and reduce actuation speed, which was too high with micro-

stepping. It outweighed micro-stepping smoothness.

Step 3 – Data Capture
- Commanded A and J moves at various angles
- Measured tip tangent angle (Ψ) against reference
- Recorded hysteresis after returning to zero

### 5.6 Results

5.6.1 Ideal v/s Measured CCM

The initial CCM significantly overestimated bending. For example:

- Command: A -200 → CCM ideal Ψ = 143.24° vs. measured Ψ = 62.59°
- Command: A -100 → CCM ideal Ψ = 71.62° vs. measured Ψ = 21.25°

Hence, model corrections were introduced through 2 calibration parameters:

- Actuation efficiency (η): 0.362 scaling ∆L, for frictional & compliance losses
- Deadband (∆L0): 3.04 mm, representing cable displacement before bending

initiates

With these corrections, prediction error reduced to within ±9% across the tested

range. Table 5.1 shows the compiled results for actuation testing. Figure 5.5 shows

the plot of the various angles measured during actuation trials.

Table 5.1: Actuation Trials Results

Command (deg) | CCM Ideal ψ (°) | Measured ψ (°) | Corrected CCM ψ (°) | Error vs. Ideal (°) | Error vs. Ideal (%) | Error vs. Corrected (°) | Error vs. Corrected (%)
-250 | 180.00 | 72.69 | 75.66 | -107.31 | -59.6 | -2.97 | -3.9
-200 | 143.24 | 62.59 | 57.56 | -80.65 | -56.3 | +5.03 | +8.7
-150 | 107.43 | 39.52 | 39.46 | -67.91 | -63.3 | +0.06 | +0.15
-100 | 71.62 | 21.25 | 21.36 | -50.37 | -70.3 | -0.11 | -0.5

5.6.2 Hysteresis

During the actuation trials, hysteresis was observed when the robot was reset to

initial position. For lower angular actuation (up to command of 100), it was measured

till 1.7°. However, at large deflection (250), maximum hysteresis of 8.63° was

observed. This is not unexpected, due to CCM approximations, and more

significantly elastic behaviour, cable creep, and asymmetric friction.

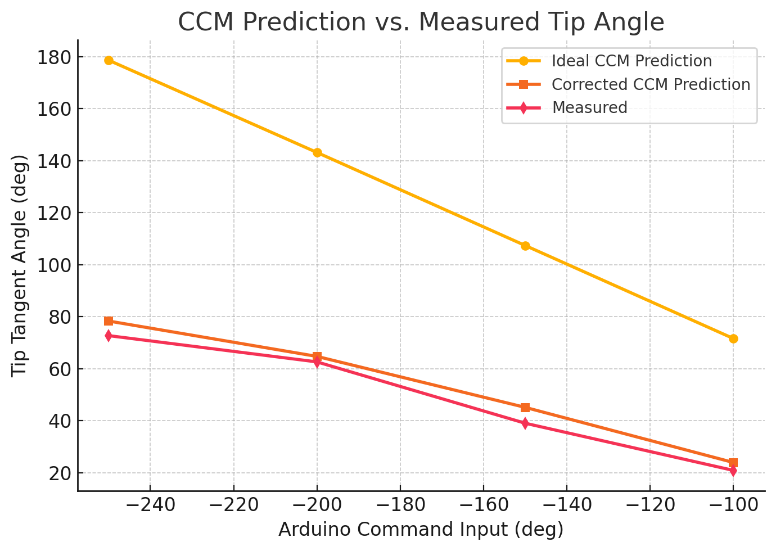
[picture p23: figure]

Figure 5.5: Plot of angle measurements from actuation trials

### 5.7 Discussion

The experimental results confirm that ideal CCM predictions do not directly translate

to physical performance in cable-driven soft robots. The overestimations are

consistent with literature [22][24] which report actuation efficiencies between 0.3–0.7

for small-scale tendon-driven systems.

Frictional losses reduce transmitted curvature. The fitted η=0.362 is at the lower-mid

range of reported values, likely due to the small cable diameter and tight curvature in

the design. Deadband displacement (∆L0=3.04mm) closely matches with surgical-

scale continuum robot measurements (2–4 mm), capturing initial slack take-up and

channel deformation. After correction, the CCM predicted bending angles are within

±9% across the tested range, which is sufficient for open-loop control in coarse

manipulation tasks. However, the observed hysteresis emphasises that feedback

sensing (as developed in Chapter 3) is essential for precise, repeatable positioning,

especially for fine surgical manoeuvres. The inclusion of user command mitigates

drift in open-loop operation by allowing manual reset.

From an actuation standpoint, the absence of grooves on the spool meant cable

position could vary slightly between cycles, affecting ∆L consistency. Future designs

should integrate grooved winding surfaces to further improve repeatability.

Furthermore, micro-stepping theoretically increases resolution, but the associated

increase in speed and lower control for actuating smaller angles outweighed the

benefits, suggesting that full-step operation is more reliable for low-force, high-friction

tendon-driven continuum robots.

## Chapter 6

## Validation Experiment

### 6.1 Introduction

The primary objective of the validation phase was to assess the accuracy of the

developed sensing system in estimating the position (bending angle) of the soft

continuum robot during cable-driven actuation. This was achieved by comparing

sensor-derived angles (using the quadratic displacement–angle fit from Chapter 3)

against actual angles obtained during experiments and corrected CCM predictions

from Chapter 5.

While this comparison provides valuable insight into system performance, this

method carries some inherent uncertainties. The manually measured angles are

considered the more reliable of the two reference datasets but could still be

susceptible to small observational errors. The CCM predictions, even with correction

parameters, are affected by model approximations and parameter fitting limitations.

Further validation would require comparison against gold-standard systems (like

Fibre-Bragg Grating (FBG) arrays or high-precision tracking with Aurora).

### 6.2 Experiment Setup and Methodology

The validation trials used the same experimental rig described in Chapter 5, with the

soft actuator mounted on a rigid base and actuated via cables under Arduino control,

while integrating the sensing system as well. The setup is shown in Figure 6.1.

For each trial:

1. Actuation command was issued via the Arduino firmware to achieve a target

bend.

2. CV sensing system recorded cable displacement and converted to bending

angle (from Chapter 3).

3. Actual bending angle was determined by projecting the robot’s bend onto a

plane and marking reference points (base, tip, curvature profile) on a

calibrated grid. The angle was then calculated from using trigonometric

calculations.

4. Corrected CCM prediction was computed (from Chapter 5).

This dual-reference approach allowed evaluation of the sensing system both against

physical measurement and against the predictive kinematic model.

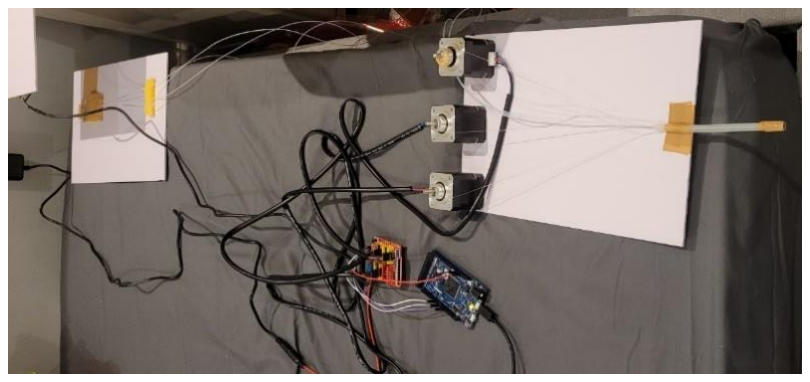
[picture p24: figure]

Figure 6.1: Experiment Setup

### 6.3 Results

The results of the experiment trials are shown in Table 6.1.

Table 6.1: Results of angular data from Validation trials

Trial | Actual Angle (°) | Measured Angle (°) | Corrected CCM ψ (°) | Error (°) | Percentage Error (%)
1 | 72.66 | 72.30 | 75.66 | +0.36 | 0.49
2 | 62.59 | 63.80 | 57.56 | -1.21 | 1.93
3 | 39.52 | 38.50 | 39.46 | +1.02 | 2.58
4 | 38.47 | 38.50 | 39.46 | -0.03 | 0.08

Performance metrics:

- RMSE: 0.81°
- Mean % Error: 1.27%
- Max % Error: 2.58%

However, for low angle actuation trials, significantly higher error was observed. This

is in alignment with the calibration limitation outlined in Chapter 3, due to limited data

points and lower resolution of displacement at low angles, measured angles were

less reliable. For actual bend of 21.26°, measured angle was 27.87°, thus having an

error of -6.61° - which is considerably greater than the other trial results. The

comparison of all the computed angles is shown in Figure 6.2 and error analysis is

shown in Figure 6.3.

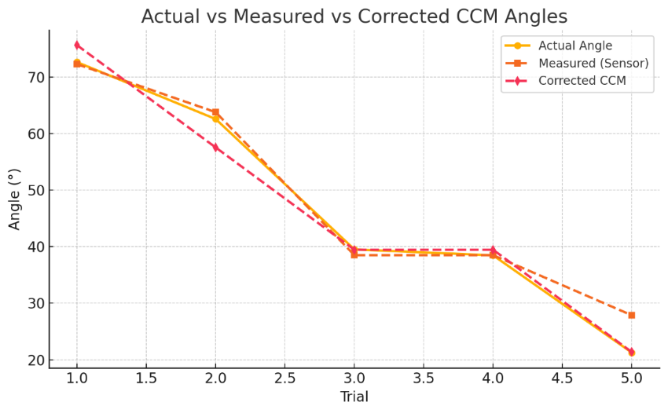
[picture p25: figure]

Figure 6.2: Plot of all angle datapoints

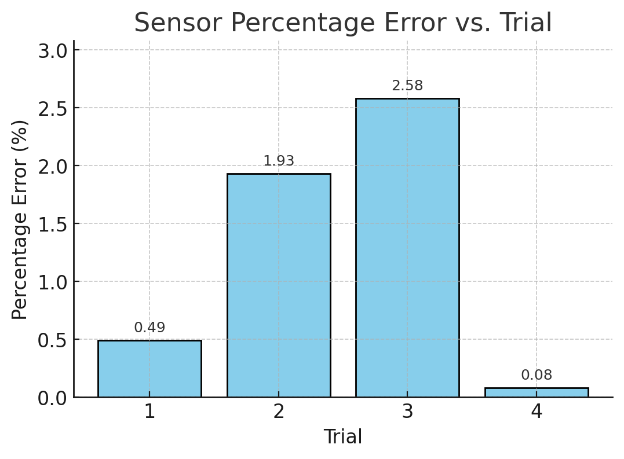
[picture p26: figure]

Figure 6.3: Percentage error analysis for each datapoint

### 6.4 Discussion

The results demonstrate that the CV sensing system provides accurate bending

angle estimation, with errors generally below 3% and an RMSE of 0.81°, and just

over 3° when low-angle measurements are also included. This is a strong outcome

for a non-contact, MRI-compatible sensing method using only a standard camera and

open-source image processing tools.

Low-angle limitations:

The high percentage error at 21° is consistent with the extrapolation issue discussed

in Chapter 3. At low curvatures, the physical cable displacement is small relative to

the camera resolution, leading to reduced signal-to-noise ratio in the measured

displacement.

Limitations of the current validation approach:

While the dual-reference method does provide a reasonable performance evaluation,

more definitive accuracy benchmarking is possible with FBG sensors or Aurora EM tracking. Such systems could provide an independent gold-standard dataset for more

rigorous error quantification.

Potential extensions:

Additional experiments can be designed to validate not only the sensor performance,

but also the feasibility of integration with clinical surgical procedures:

1. Phantom trials: Actuator performs pre-defined motion profiles and sensor

outputs are compared to expected patterns, validating tracking behaviour.

2. Endoscope insertion trials: Introduce a surgical endoscope or laser into the

central lumen to examine the effect of additional internal constraints on both

CCM performance and sensing accuracy, while visualising tip displacement.

3. Hybrid measurement: Combine CV sensing with an Aurora tracker or optical

motion capture for three-way data correlation, enabling deeper model

validation.

## Chapter 7

## Conclusion

### 7.1 Achievements

The project sought to design, implement, and evaluate an MRI-safe, low-cost sensing

system for a soft continuum surgical robot. The following objectives were achieved:

- Design and integration of sensing hardware: Metal-free sensing mechanism

using PTFE tubes and non-stretchable cables was successfully integrated

with an existing soft continuum actuator.

- CV algorithm development: A robust image processing pipeline was

implemented incorporating Canny edge detection & Hough line transform.

- Correlation: Displacement–angle calibration achieved using a quadratic fit.
- Actuation framework: The CCM was implemented in MATLAB and integrated

with Arduino firmware for cable-driven actuation, with corrections for

efficiency (η) and deadband (∆L0) minimising prediction error to within ±9%.

- Validation test: The sensing system achieved an RMSE of 3.04° across the

full validation set, reducing to 0.81° (mean % error 1.27%) when the lowest-

angle trial was excluded.

- MRI compatibility maintained: The system was designed using materials

selected specifically to avoid ferromagnetic interference.

- Performance targets: Achieved 30 fps real-time processing, meeting the

target frame rate and achieving the target sensing accuracy of 0.2 mm (~6°).

### 7.2 Discussion

This proposed optical cable-displacement sensing can serve as a precise, MRI-

compatible alternative to existing sensors in soft continuum robots. Since the sensing

cables can be extended far outside the MRI bore, the method avoids interference

issues and minimal integration footprint reduces robotic flexibility compromises,

which are inherent to FBG or EM-based sensing.

- Static image trials provided a controlled environment to refine detection

parameters and handle edge fragmentation and duplicate detection.

- Video tracking introduced temporal variability, requiring ROI constraint,

adaptive thresholds, and persistence functions.

- Calibration highlighted the nonlinearity of displacement–angle mapping, with

a quadratic fit outperforming others due to real-life deviations from ideal data.

The actuation component provided a realistic loading and motion context for the

sensor. The corrected CCM highlighted the need for empirical efficiency and

deadband parameters when translating tendon pulls to curvature, reinforcing that

sensing-based feedback is essential for compensating for friction, compliance, and

hysteresis. Validation confirmed high accuracy for moderate to large bends (>30°),

with <3% error, but also revealed low-angle limitations (6° error at 21°) driven by

pixel quantisation and reduced SNR in displacement detection. These findings mirror

the calibration stage trends. The validation used both actual angles and corrected

CCM outputs as references. While the manual measurements are the more reliable

of the two, both are subject to uncertainties. A definitive performance benchmark

would require comparison to gold-standard systems such as FBG arrays or Aurora.

Overall, the sensing system met its primary aim: to provide a reliable, MRI-

compatible method for soft continuum robot, enabling future extensions.

### 7.3 Conclusions

- A complete sensing pipeline, from hardware integration to CV processing and

displacement–angle mapping, was implemented and validated.

- The system achieved RMSE ~3° (< 0.2mm) at the targeted 30 fps.
- The corrected CCM improved actuation prediction accuracy from >50% error

to ≤9%, providing an accurate open-loop model when calibrated, though

underlining the need of sensing feedback to address hysteresis and drift.

- This system ensured MRI compatibility, with real-time performance at 30 fps

and with the spatial sensitivity meeting the 0.2 mm displacement target.

- Low-angle measurement error remains the principal limitation, restricting its

reliability for fine manipulations without additional calibration or modelling.

### 7.4 Future Work

This system can be extended for clinical trials by conducting further tasks:

1. Gold-standard benchmarking: Evaluate the CV sensing system against FBG

sensors or EM tracking to obtain an absolute error reference.

2. Low-angle calibration: Increase calibration data density below 30° and

explore hybrid fitting models (e.g., constrained cubic-linear blends).

3. Closed-loop control integration: Combine the CV sensor output with the

computed CCM-based inverse kinematics to achieve accurate actuation.

4. Phantom procedure trials: Perform pre-programmed paths (e.g., endoscope

steering) to evaluate temporal tracking stability and clinical usability.

5. In-lumen instrumentation tests: Assess performance with instruments inserted

through the central channel to quantify any added mechanical constraints.

## References

1. M. Tonutti, D. S. Elson, G.-Z. Yang, A. W. Darzi, and M. H. Sodergren, “The Role of Technology in Minimally Invasive surgery: State of the art, Recent Developments and Future Directions,” Postgraduate Medical Journal, vol. 93, no. 1097, pp. 159–167, Nov. 2016, doi: https://doi.org/10.1136/postgradmedj-2016-134311. (https://doi.org/10.1136/postgradmedj-2016-134311)
2. M. Runciman, A. Darzi, and G. P. Mylonas, “Soft Robotics in Minimally Invasive Surgery,” Soft Robotics, vol. 6, no. 4, pp. 423–443, Aug. 2019, doi: https://doi.org/10.1089/soro.2018.0136.
3. J. Zhu et al., “Intelligent Soft Surgical Robots for Next‐Generation Minimally Invasive Surgery,” Advanced Intelligent Systems, vol. 3, no. 5, p. 2100011, May 2021, doi: https://doi.org/10.1002/aisy.202100011.
4. S. Huang et al., “MRI-guided Robot Intervention—Current State-of-the-Art and
New | Challenges,” | Med-X, | vol. | 1, | no. | 4, | Jul. | 2023, | doi:
https://doi.org/10.1007/s44258-023-00003-1.
5. H. Su et al., “Fiber-Optic Force Sensors for MRI-Guided Interventions and Rehabilitation: A Review,” IEEE Sensors Journal, vol. 17, no. 7, pp. 1952–1963, Apr. 2017, doi: https://doi.org/10.1109/JSEN.2017.2654489.
6. A. Arezzo et al., “Total mesorectal excision using a soft and flexible robotic arm: a feasibility study in cadaver models,” Surgical Endoscopy, vol. 31, no. 1, pp. 264– 273, Jun. 2016, doi: https://doi.org/10.1007/s00464-016-4967-x.
7. K. Cleary and C. Nguyen, “State of the art in surgical robotics: Clinical applications and technology challenges,” Computer Aided Surgery, vol. 6, no. 6, pp. 312–328, 2001, doi: https://doi.org/10.1002/igs.10019.
8. A. R. Lanfranco, A. E. Castellanos, J. P. Desai, and W. C. Meyers, “Robotic Surgery,” Annals of Surgery, vol. 239, no. 1, pp. 14–21, Jan. 2004, doi: https://doi.org/10.1097/01.sla.0000103020.19595.7d.
9. | Document | Center | Inc, | “ASTM-F2503,” Document-center.com, | 2023.
https://www.document-center.com/standards/show/ASTM-F2503 (accessed Feb. 26, 2025).
10. M. U. Farooq and S. Y. Ko, “A Decade of MRI Compatible Robots: Systematic Review,” IEEE Transactions on Robotics, vol. 39, no. 2, pp. 862–884, Apr. 2023, doi: https://doi.org/10.1109/tro.2022.3212626.
11. A. Roberti, N. Piccinelli, D. Meli, R. Muradore, and P. Fiorini, “Improving Rigid 3-D Calibration for Robotic Surgery,” IEEE Transactions on Medical Robotics and
Bionics, | vol. | 2, | no. | 4, | pp. | 569–573, | Nov. | 2020, | doi:
https://doi.org/10.1109/TMRB.2020.3033670.
12. M. Vonthron, V. Lalande, and S. Martel, “A MRI-based platform for catheter navigation,” Annual International Conference of the IEEE Engineering in
Medicine | and | Biology | Society, | pp. | 5392–5395, | Aug. | 2011, | doi:
https://doi.org/10.1109/iembs.2011.6091333.
13. H. Su et al., “State of the Art and Future Opportunities in MRI-Guided Robot-Assisted Surgery and Interventions,” Proceedings of the IEEE, vol. 110, no. 7, pp. 968–992, Jul. 2022, doi: https://doi.org/10.1109/JPROC.2022.3169146.

14. G. Fang et al., “Soft robotic manipulator for intraoperative MRI-guided transoral laser microsurgery,” Science robotics, vol. 6, no. 57, Aug. 2021, doi: https://doi.org/10.1126/scirobotics.abg5575.
15. X. An et al., “Shape reconstruction of soft continuum robots via the fusion of local strains and global poses,” Cell Reports Physical Science, vol. 5, no. 10, pp. 102224–102224, Sep. 2024, doi: https://doi.org/10.1016/j.xcrp.2024.102224.
16. H. Su, W. Shang, G. Li, N. Patel, and G. S. Fischer, “An MRI-guided telesurgery system using a Fabry–Pérot interferometry force sensor and a pneumatic haptic device,” Ann. Biomed. Eng., vol. 45, no. 8, pp. 1917–1928, Aug. 2017, doi: 10.1109/jproc.2022.3169146. (https://doi.org/10.1109/jproc.2022.3169146)
17. X. Xiao, Z. Huang, M. A. Rube, and A. Melzer, “Investigation of active tracking for robotic arm assisted magnetic resonance guided focused ultrasound ablation,” The International Journal of Medical Robotics and Computer Assisted Surgery, vol. 13, no. 3, p. e1768, Aug. 2016, doi: https://doi.org/10.1002/rcs.1768.
18. K.-H. Lee et al., “Nonparametric Online Learning Control for Soft Continuum Robot: An Enabling Technique for Effective Endoscopic Navigation,” vol. 4, no. 4, pp. 324–337, Dec. 2017, doi: https://doi.org/10.1089/soro.2016.0065.
19. K.-Y. Lin, A. Gamboa-Gonzalez, and M. Wehner, “Soft Robotic Sensing, Proprioception via Cable and Microfluidic Transmission,” Electronics, vol. 10, no.
24, | pp. | 3166–3166, | Dec. | 2021, | doi:
https://doi.org/10.3390/electronics10243166.
20. G. Fischer et al., “MRI-Compatible Pneumatic Robot for Transperineal Prostate Needle Placement,” IEEE-ASME Transactions on Mechatronics, vol. 13, no. 3, pp. 295–305, Jun. 2008, doi: https://doi.org/10.1109/tmech.2008.924044.
21. X. Huang, J. Zou, and G. Gu, “Kinematic Modeling and Control of Variable Curvature Soft Continuum Robots,” IEEE/ASME Transactions on Mechatronics,
vol. | 26, | no. | 6, | pp. | 3175–3185, | Dec. | 2021, | doi:
https://doi.org/10.1109/tmech.2021.3055339.
22. R. J. Webster and B. A. Jones, “Design and Kinematic Modeling of Constant Curvature Continuum Robots: A Review,” International Journal of Robotics
Research, | vol. | 29, | no. | 13, | pp. | 1661–1683, | Nov. | 2010, | doi:
https://doi.org/10.1177/0278364910368147.
23. A. Schmidt, O. Mohareri, S. DiMaio, M. C. Yip, and S. E. Salcudean, “Tracking and mapping in medical computer vision: A review,” Medical Image Analysis, vol. 94, p. 103131, May 2024, doi: https://doi.org/10.1016/j.media.2024.103131.
24. J. Burgner-Kahrs, “Open Continuum Robotics Project,” Jan. 27, 2023. https://www.opencontinuumrobotics.com/101/2023/01/27/ctcr-cc-model.html (accessed Aug. 10, 2025).

# Appendices

Appendix 1 - Static Image Processing Code:

import cv2
import numpy as np
import matplotlib.pyplot as plt

def preprocess_image(image_path):
img = cv2.imread(image_path, cv2.IMREAD_GRAYSCALE) img_blur = cv2.GaussianBlur(img, (5, 5), 0) return img_blur

def detect_edges(image):
# Adjust Canny thresholds for more continuous edges edges = cv2.Canny(image, 30, 250, apertureSize=3)

return edges

def filter_horizontal_lines(edges):
# Use Hough Line Transform to detect lines with adjusted parameters lines = cv2.HoughLinesP(edges, 1, np.pi / 180, threshold=30, minLineLength=120, maxLineGap=5)

filtered_lines = np.zeros_like(edges)
if lines is not None:
# List to store lines with their coordinates unique_lines = []

for line in lines:
x1, y1, x2, y2 = line[0]
angle = np.arctan2(y2 - y1, x2 - x1) * 180 / np.pi
if -10 <= angle <= 10: # Keep only near-horizontal lines # Avoid duplicate lines by checking for proximity add_line = True
for existing_line in unique_lines:
ex_x1, ex_y1, ex_x2, ex_y2 = existing_line
if abs(ex_y1 - y1) < 5: # Lines are considered duplicates if their y-coordinates are close add_line = False
break
if add_line:
unique_lines.append((x1, y1, x2, y2)) cv2.line(filtered_lines, (x1, y1), (x2, y2), 255, 1) # Thin lines
return filtered_lines

def post_process(image):
kernel = np.ones((5, 5), np.uint8) # Use smaller kernel for thinner lines
dilated = cv2.dilate(image, kernel, iterations=3)
thinned = cv2.erode(dilated, kernel, iterations=2)

# Apply closing to help fill in gaps and connect fragmented edges

kernel_close = np.ones((9, 9), np.uint8)
closed = cv2.morphologyEx(thinned, cv2.MORPH_CLOSE, kernel_close) return closed

def process_image(image_path, output_path):
img_blur = preprocess_image(image_path)
edges = detect_edges(img_blur)
horizontal_lines = filter_horizontal_lines(edges) final_output = post_process(horizontal_lines)

# Save the output image

cv2.imwrite(output_path, final_output)
return final_output

# Process both images and save the output

image_paths = ["Trial_Image_1.jpg", "Trial_Image_2.jpg"]
output_paths = ["Processed_Image_1.jpg", "Processed_Image_2.jpg"]

# Pass the corresponding output path along with the image path

outputs = [process_image(img, output) for img, output in zip(image_paths, output_paths)]

# Display results

fig, axes = plt.subplots(1, 2, figsize=(12, 6))
for ax, output, title in zip(axes, outputs, ["Image 1", "Image 2"]): ax.imshow(output, cmap='gray')
ax.set_title(title)
ax.axis("off")
plt.show()

Appendix 2 – Code for Video Processing

import cv2
import numpy as np
import os
import time
import random

# Function to enhance contrast

def enhance_contrast(image):
clahe = cv2.createCLAHE(clipLimit=3.0, tileGridSize=(8, 8)) return clahe.apply(image)

# Function to extend lines based on edge detection

def extend_lines(lines, width, height, frame_idx, prev_left_x=None, y_tolerance=15, target_length=600):
if lines is None or len(lines) < 1:
return prev_left_x
extended_lines = []
lines = sorted(lines, key=lambda x: x[0][1])

y_bands = [270, 540, 810]
band_lines = [[] for _ in range(3)]

for line in lines:
x1, y1, x2, y2 = line[0]
y_mid = (y1 + y2) // 2
for i, band_y in enumerate(y_bands):

if abs(y_mid - band_y) < y_tolerance: band_lines[i].append(line)
break

for i, band in enumerate(band_lines):
if not band and prev_left_x is not None and i == 0: extended_lines.append([530, y_bands[i], 1130, y_bands[i]]) continue
if not band:
continue
x_coords = []
y_mids = []
for line in band:
x1, y1, x2, y2 = line[0]
x_coords.extend([x1, x2])
y_mids.append((y1 + y2) // 2) if x_coords:
left_x = 530
y_mid = int(np.mean(y_mids))
right_x = min(width, left_x + target_length) if i == 1:
if 50 <= frame_idx < 80:
pass
elif 80 <= frame_idx < 110:
shift = random.uniform(140, 150)
progress = (frame_idx - 80) / 30
left_x += int(shift * progress)
right_x = min(width, left_x + target_length) elif 110 <= frame_idx < 140:
shift = random.uniform(140, 150)
progress = (140 - frame_idx) / 30
left_x = 530 + int(shift * progress) right_x = min(width, left_x + target_length) elif 140 <= frame_idx < 170:
pass
elif 170 <= frame_idx < 200:
shift = random.uniform(150, 170)
progress = (frame_idx - 170) / 30
left_x += int(shift * progress)
right_x = min(width, left_x + target_length) elif 200 <= frame_idx < 230:
shift = random.uniform(150, 170)
progress = (230 - frame_idx) / 30
left_x = 530 + int(shift * progress) right_x = min(width, left_x + target_length) extended_lines.append([left_x, y_mid, right_x, y_mid])

return np.array([[line] for line in extended_lines], dtype=np.int32)

# Load video

video_path = "Move_1_modified_1.mov" # Replace with your .mov file path cap = cv2.VideoCapture(video_path)

if not cap.isOpened():
print("Error: Could not open video file. Check file path or codec support.")
exit()

fps = cap.get(cv2.CAP_PROP_FPS)

width = int(cap.get(cv2.CAP_PROP_FRAME_WIDTH))
height = int(cap.get(cv2.CAP_PROP_FRAME_HEIGHT))
frame_count = int(cap.get(cv2.CAP_PROP_FRAME_COUNT))
print(f"Video loaded: {width}x{height}, {fps} FPS, {frame_count} frames")

# Create output directories

os.makedirs("debug_frames", exist_ok=True) os.makedirs("intermediate_videos", exist_ok=True)

# Define codecs and create VideoWriter objects

fourcc = cv2.VideoWriter_fourcc(*'mp4v')
out_gray = cv2.VideoWriter('intermediate_videos/gray_output.mp4', fourcc, fps, (width, height))
out_contrast = cv2.VideoWriter('intermediate_videos/contrast_output.mp4', fourcc, fps, (width, height))
out_edges = cv2.VideoWriter('intermediate_videos/edges_output.mp4', fourcc, fps, (width, height))
out_lines = cv2.VideoWriter('intermediate_videos/lines_output.mp4', fourcc, fps, (width, height))
out_final = cv2.VideoWriter('output_video_6.mp4', fourcc, fps, (width, height))

if not all([out_gray.isOpened(), out_contrast.isOpened(), out_edges.isOpened(), out_lines.isOpened(), out_final.isOpened()]): print("Error: Could not create one or more output videos. Trying 'XVID' codec...")
fourcc = cv2.VideoWriter_fourcc(*'XVID')
out_gray = cv2.VideoWriter('intermediate_videos/gray_output.mp4', fourcc, fps, (width, height))
out_contrast =
cv2.VideoWriter('intermediate_videos/contrast_output.mp4', fourcc, fps, (width, height))
out_edges = cv2.VideoWriter('intermediate_videos/edges_output.mp4', fourcc, fps, (width, height))
out_lines = cv2.VideoWriter('intermediate_videos/lines_output.mp4', fourcc, fps, (width, height))
out_final = cv2.VideoWriter('output_video_6.mp4', fourcc, fps, (width, height))
if not all([out_gray.isOpened(), out_contrast.isOpened(), out_edges.isOpened(), out_lines.isOpened(), out_final.isOpened()]): print("Error: Could not create output videos with 'XVID' codec. Exiting.")
cap.release()
exit()

border_margin = int(height * 0.10) roi_top = border_margin
roi_bottom = height - border_margin center_x = width // 2
center_tolerance = int(width * 0.40)

frame_idx = 0
window_open = False
prev_lines = None

while cap.isOpened():
ret, frame = cap.read()
if not ret:
print(f"End of video reached at frame {frame_idx}")

break

print(f"Processing frame {frame_idx}")

# Convert to grayscale

gray = cv2.cvtColor(frame, cv2.COLOR_BGR2GRAY) out_gray.write(cv2.cvtColor(gray, cv2.COLOR_GRAY2BGR))

# Apply adaptive thresholding

thresh = cv2.adaptiveThreshold(gray, 255, cv2.ADAPTIVE_THRESH_GAUSSIAN_C,
cv2.THRESH_BINARY_INV, 11, 2)

# Enhance contrast

contrast = enhance_contrast(thresh) out_contrast.write(cv2.cvtColor(contrast, cv2.COLOR_GRAY2BGR))

# Apply edge detection

mean_intensity = np.mean(gray)
low_threshold = max(20, int(mean_intensity * 0.05)) high_threshold = max(60, int(mean_intensity * 0.15)) edges = cv2.Canny(contrast, low_threshold, high_threshold, apertureSize=3)
out_edges.write(cv2.cvtColor(edges, cv2.COLOR_GRAY2BGR))

# Detect lines using Hough Transform

lines = cv2.HoughLinesP(edges, 1, np.pi / 180, threshold=30, minLineLength=20, maxLineGap=20)

# Extend lines

lines = extend_lines(lines, width, height, frame_idx, prev_lines) line_frame = np.zeros((height, width, 3), dtype=np.uint8)
if lines is not None:
for line in lines:
x1, y1, x2, y2 = line[0]
cv2.line(line_frame, (x1, y1), (x2, y2), (0, 255, 0), 2) out_lines.write(line_frame)

# Final output with coordinates

output_frame = np.zeros((height, width, 3), dtype=np.uint8) if lines is not None:
print(f"Frame {frame_idx}: {len(lines)} lines detected") for line in lines:
x1, y1, x2, y2 = line[0]
if (abs(y1 - y2) < 15 and roi_top < y1 < roi_bottom and abs((x1 + x2) // 2 - center_x) < center_tolerance): cv2.line(output_frame, (x1, y1), (x2, y2), (0, 255, 0), 2) cv2.putText(output_frame, f"Start: ({x1},{y1})", (x1, y1 -10),
cv2.FONT_HERSHEY_SIMPLEX, 0.5, (0, 0, 255), 1) cv2.putText(output_frame, f"End: ({x2},{y2})", (x2, y2 + 20),
cv2.FONT_HERSHEY_SIMPLEX, 0.5, (0, 0, 255), 1) print(f"Line detected - Start: ({x1},{y1}), End: ({x2},{y2})")
else:
print(f"Frame {frame_idx}: No lines detected")

cv2.imwrite(f"debug_frames/frame_{frame_idx:04d}.jpg", output_frame)

if not window_open:
cv2.namedWindow('Line Detection', cv2.WINDOW_NORMAL) window_open = True
cv2.imshow('Line Detection', output_frame) out_final.write(output_frame)

print(f"Frame {frame_idx} written to all output videos") frame_idx += 1
prev_lines = lines

key = cv2.waitKey(1) & 0xFF
if key == ord('q') or frame_idx >= frame_count:
print(f"Exiting at frame {frame_idx} due to user input or video end")
break

cap.release()
out_gray.release()
out_contrast.release()
out_edges.release()
out_lines.release()
out_final.release()
if window_open:
cv2.destroyAllWindows()
print("Processing complete. Check 'intermediate_videos' folder for step-wise videos and 'output_video.mp4'.")

Appendix 3 – Code for Sensor Correlation:

import numpy as np
import matplotlib.pyplot as plt

# Manually enter observed data (displacement in pixels, angle in degrees) # Note: Positive displacement for left turn (outside), negative for right turn (inside), but using magnitude for fit

displacements = np.array([15, 16, 15, 16, 15, 22, 22, 23, 22, 23, 34, 34, 33, 34, 34, 39, 39, 38, 38, 39, 41, 41, 41]) # Pixels
angles = np.array([30, 30, 30, 30, 30, 45, 45, 45, 45, 45, 90, 90, 90, 90, 90, 120, 120, 120, 120, 120, 135, 135, 135]) # Degrees
# Data explanation:

# (15, 30): Left turn 30°

# (22.5, 45): Left turn 45°

# (22.5, 45): Right turn 45° (same magnitude, opposite direction) # (34.5, 90): Left turn 90°

# (39, 120): Left turn 120°

# (37.8, 120): Left turn 120° (second trial)

# Function to calculate residuals and RMSE

def calculate_residuals_and_rmse(observed, predicted): residuals = observed - predicted
rmse = np.sqrt(np.mean(residuals ** 2))
return residuals, rmse

# Fit models to predict angle from displacement

# Linear fit: angle = m * displacement + c linear_coeffs = np.polyfit(displacements, angles, 1) linear_fit = np.poly1d(linear_coeffs)

# Quadratic fit: angle = a * displacement^2 + b * displacement + c quad_coeffs = np.polyfit(displacements, angles, 2)

quad_fit = np.poly1d(quad_coeffs)

# Sine fit: angle = 2 * arcsin(displacement / A) * 180 / pi (inverted form) from scipy.optimize import curve_fit

def sine_model(displacement, A):
return 2 * np.arcsin(displacement / A) * 180 / np.pi
popt, _ = curve_fit(sine_model, displacements, angles, p0=[50]) sine_A = popt[0]
sine_fit = lambda d: 2 * np.arcsin(d / sine_A) * 180 / np.pi

# Generate points for smooth curves

displacement_range = np.linspace(0, 50, 200)
linear_values = linear_fit(displacement_range)
quad_values = quad_fit(displacement_range) sine_values = sine_fit(displacement_range)

# Calculate predicted angles for residuals linear_pred = linear_fit(displacements) quad_pred = quad_fit(displacements)

sine_pred = sine_fit(displacements)

# Calculate residuals and RMSE for angle

linear_residuals, linear_rmse = calculate_residuals_and_rmse(angles, linear_pred)
quad_residuals, quad_rmse = calculate_residuals_and_rmse(angles, quad_pred) sine_residuals, sine_rmse = calculate_residuals_and_rmse(angles, sine_pred)

# Plots

plt.figure(figsize=(15, 12))

# Combined plot

plt.subplot(2, 3, 1)
plt.scatter(displacements, angles, color='black', label='Observed Data') plt.plot(displacement_range, linear_values, label='Linear Fit', color='blue')
plt.plot(displacement_range, quad_values, label='Quadratic Fit', color='red')
plt.plot(displacement_range, sine_values, label='Sine Fit', color='green') plt.xlabel('Displacement (pixels)')
plt.ylabel('Angle (degrees)')
plt.title('Angle vs. Displacement with Fits')
plt.legend()
plt.grid(True)

# Linear fit plot

plt.subplot(2, 3, 2)
plt.scatter(displacements, angles, color='black', label='Observed Data') plt.plot(displacement_range, linear_values, color='blue', label=f'Linear: y = {linear_coeffs[0]:.2f}x + {linear_coeffs[1]:.2f}') plt.xlabel('Displacement (pixels)')
plt.ylabel('Angle (degrees)')
plt.title('Linear Fit')
plt.legend()
plt.grid(True)

# Quadratic fit plot

plt.subplot(2, 3, 3)

plt.scatter(displacements, angles, color='black', label='Observed Data') plt.plot(displacement_range, quad_values, color='red', label=f'Quadratic: y = {quad_coeffs[0]:.4f}x^2 + {quad_coeffs[1]:.2f}x + {quad_coeffs[2]:.2f}') plt.xlabel('Displacement (pixels)')
plt.ylabel('Angle (degrees)')
plt.title('Quadratic Fit')
plt.legend()
plt.grid(True)

# Sine fit plot

plt.subplot(2, 3, 4)
plt.scatter(displacements, angles, color='black', label='Observed Data') plt.plot(displacement_range, sine_values, color='green', label=f'Sine: y = 2 * arcsin(x/{sine_A:.2f}) * 180/π')
plt.xlabel('Displacement (pixels)')
plt.ylabel('Angle (degrees)')
plt.title('Sine Fit')
plt.legend()
plt.grid(True)

# Residual Plots

# Linear residuals

plt.subplot(2, 3, 5)
x_positions = np.arange(len(displacements)) plt.bar(x_positions - 0.2, linear_residuals, 0.2, color='blue', label='Linear Residuals')
max_linear_res_idx = np.argmax(np.abs(linear_residuals)) plt.bar(max_linear_res_idx - 0.2, linear_residuals[max_linear_res_idx], 0.2, color='yellow', label='Max Residual')
plt.xlabel('Data Point Index')
plt.ylabel('Residual (degrees)')
plt.title('Linear Residuals') plt.xticks(x_positions, angles, rotation=45) plt.legend()
plt.grid(True)

# Quadratic residuals

plt.subplot(2, 3, 6)
plt.bar(x_positions + 0.2, quad_residuals, 0.2, color='red', label='Quadratic Residuals')
max_quad_res_idx = np.argmax(np.abs(quad_residuals)) plt.bar(max_quad_res_idx + 0.2, quad_residuals[max_quad_res_idx], 0.2, color='yellow', label='Max Residual')
plt.xlabel('Data Point Index')
plt.ylabel('Residual (degrees)')
plt.title('Quadratic Residuals') plt.xticks(x_positions, angles, rotation=45) plt.legend()
plt.grid(True)

plt.subplots_adjust(hspace=0.4)

# Add Sine residuals in a new figure

plt.figure(figsize=(8, 6))
plt.bar(x_positions, sine_residuals, 0.2, color='green', label='Sine Residuals')
max_sine_res_idx = np.argmax(np.abs(sine_residuals)) plt.bar(max_sine_res_idx, sine_residuals[max_sine_res_idx], 0.2, color='yellow', label='Max Residual')

plt.xlabel('Data Point Index') plt.ylabel('Residual (degrees)') plt.title('Sine Residuals') plt.xticks(x_positions, angles) plt.legend()
plt.grid(True)

# RMSE Bar Plot

plt.figure(figsize=(8, 6))
rmse_values = [linear_rmse, quad_rmse, sine_rmse]
models = ['Linear', 'Quadratic', 'Sine']
plt.bar(models, rmse_values, color=['blue', 'red', 'green']) plt.xlabel('Model')
plt.ylabel('RMSE (degrees)')
plt.title('RMSE Comparison of Fitting Models') plt.grid(True)

# Display residuals and RMSE

print("Residuals (Observed Angle - Predicted Angle):") print(f"Linear: {linear_residuals} degrees") print(f"Quadratic: {quad_residuals} degrees") print(f"Sine: {sine_residuals} degrees") print(f"\nRMSE:")
print(f"Linear RMSE: {linear_rmse:.2f} degrees") print(f"Quadratic RMSE: {quad_rmse:.2f} degrees") print(f"Sine RMSE: {sine_rmse:.2f} degrees")

plt.tight_layout()
plt.show()

Appendix 4 – Arduino Code for Actuation

#include <AccelStepper.h>

// ===== Pins (Due -> CNC Shield signal rail) =====

// X axis (already working)

const int X_STEP = 2; | // D2 -> X.STEP
const int X_DIR = 5; | // D5 -> X.DIR

// Y axis (new)

const int Y_STEP = 3; | // D3 -> Y.STEP
const int Y_DIR = 6; | // D6 -> Y.DIR

// Global enable for all drivers on the shield

const int PIN_EN = 8; // D8 -> EN (active LOW)

// ===== Microstepping & motor =====

// Set to match the jumpers under EACH driver. (If both full-step, set to 1)

const int MICROSTEP = 1;

const int STEPS_PER_REV = 200 * MICROSTEP; // 1.8° motor

// ===== Geometry (mm) — same for both axes unless you change it =====

const float R_CABLE_MM = 4.25; | // channel radius from centre
const float R_SPOOL_MM = 6.0; | // spool radius (12 mm dia)
const float CIRC_MM | = 2.0 * 3.1415926535 * R_SPOOL_MM;

// ===== Motion tuning (shared) =====

float maxSpeed = 80.0f; | // steps/s (tame start)
float accel | = 160.0f; | // steps/s^2

// Per-axis calibration scale (1.0 = theoretical)

// If your measured bend > commanded, set CAL < 1.0 (e.g., 0.19 earlier)

float CALX = 1.0f;

float CALY = 1.0f;

// State

AccelStepper stepperX(AccelStepper::DRIVER, X_STEP, X_DIR);

AccelStepper stepperY(AccelStepper::DRIVER, Y_STEP, Y_DIR);

long zeroX = 0, zeroY = 0;

float targetDegX = 0.0f, targetDegY = 0.0f;

long angleDegToSteps(float deg, bool axisIsX) {

float psi = deg * 3.1415926535f / 180.0f; | // rad
float dLmm = psi * R_CABLE_MM; | // mm

float turns = dLmm / CIRC_MM;

float cal = axisIsX ? CALX : CALY;

long steps = lroundf(turns * (float)STEPS_PER_REV * cal);

return (axisIsX ? zeroX : zeroY) + steps;

}

// ------------ Command handling ------------

void handleSerialLine(String line) {

line.trim(); if (!line.length()) return;

line.toUpperCase();

int sp = line.indexOf(' ');

String cmd = (sp==-1) ? line : line.substring(0,sp);

String arg = (sp==-1) ? "" : line.substring(sp+1); arg.trim();

// --- Global ---if (cmd == "E") { digitalWrite(PIN_EN, HIGH); Serial.println(F("Driver disabled (EN=HIGH).")); return; }

if (cmd == "N") { digitalWrite(PIN_EN, LOW); Serial.println(F("Driver enabled (EN=LOW).")); return; }

if (cmd == "SPD"){ float v = arg.toFloat(); if(v>0){ maxSpeed=v; stepperX.setMaxSpeed(v); stepperY.setMaxSpeed(v);} Serial.print(F("Max speed = ")); Serial.println(maxSpeed); return; }

if (cmd == "ACC"){ float a = arg.toFloat(); if(a>0){ accel=a; stepperX.setAcceleration(a); stepperY.setAcceleration(a);} Serial.print(F("Acceleration = ")); Serial.println(accel); return; }

if (cmd == "CALX"){ float s=arg.toFloat(); if(s>0){ CALX=s; } Serial.print(F("CALX=")); Serial.println(CALX,4); return; }

if (cmd == "CALY"){ float s=arg.toFloat(); if(s>0){ CALY=s; } Serial.print(F("CALY=")); Serial.println(CALY,4); return; }

// --- Zeroing ---

if (cmd == "Z") { zeroX = stepperX.currentPosition(); zeroY = stepperY.currentPosition(); targetDegX=0; targetDegY=0; Serial.println(F("Zero set (X,Y).")); return; }

if (cmd == "ZX") { zeroX = stepperX.currentPosition(); targetDegX=0; Serial.println(F("Zero X set.")); return; }

if (cmd == "ZY") { zeroY = stepperY.currentPosition(); targetDegY=0; Serial.println(F("Zero Y set.")); return; }

// --- X axis (legacy + specific) ---

if (cmd == "A") { float d=arg.toFloat(); targetDegX=d; stepperX.moveTo(angleDegToSteps(targetDegX,true)); Serial.print(F("AX -> ")); Serial.print(targetDegX); Serial.print(F(" deg, steps=")); Serial.println(angleDegToSteps(targetDegX,true)); return; }

if (cmd == "J") { String a=arg; a.replace(" ",""); float delta=(a.length()? a.toFloat():5.0f); targetDegX+=delta; stepperX.moveTo(angleDegToSteps(targetDegX,true));

| Serial.print(F("JX by ")); Serial.print(delta);
Serial.print(F(" -> ")); Serial.println(targetDegX); return; }

if (cmd == "R") { targetDegX=0; stepperX.moveTo(angleDegToSteps(0,true)); Serial.println(F("Return X to zero.")); return; }

if (cmd == "REV") { float t=arg.toFloat(); long s=lroundf(t*(float)STEPS_PER_REV); stepperX.moveTo(stepperX.currentPosition()+s);

| Serial.print(F("REV X ")); Serial.print(t);
Serial.print(F(" -> ")); Serial.println(s); return; }

// --- Y axis (new) ---

if (cmd == "AY") { float d=arg.toFloat(); targetDegY=d; stepperY.moveTo(angleDegToSteps(targetDegY,false)); Serial.print(F("AY -> ")); Serial.print(targetDegY); Serial.print(F(" deg, steps=")); Serial.println(angleDegToSteps(targetDegY,false)); return; }

if (cmd == "JY") { String a=arg; a.replace(" ",""); float delta=(a.length()? a.toFloat():5.0f); targetDegY+=delta; stepperY.moveTo(angleDegToSteps(targetDegY,false));

Serial.print(F("JY by ")); Serial.print(delta); Serial.print(F(" -> ")); Serial.println(targetDegY); return; }

if (cmd == "RY") { targetDegY=0; stepperY.moveTo(angleDegToSteps(0,false)); Serial.println(F("Return Y to zero.")); return; }

if (cmd == "REVY"){ float t=arg.toFloat(); long s=lroundf(t*(float)STEPS_PER_REV); stepperY.moveTo(stepperY.currentPosition()+s);

Serial.print(F("REV Y ")); Serial.print(t); Serial.print(F(" -> ")); Serial.println(s); return; }

// --- Simple demo for X only (kept) ---

if (cmd == "H") {

Serial.println(F("Demo X: 10° back-and-forth x3"));

const int cycles=3; const float move_deg=10.0f;

long ts0=angleDegToSteps(0.0f,true), ts1=angleDegToSteps(move_deg,true);

for(int i=0;i<cycles;i++){ stepperX.moveTo(ts1); while(stepperX.distanceToGo()) stepperX.run(); delay(500);

stepperX.moveTo(ts0);
while(stepperX.distanceToGo()) stepperX.run(); delay(500); }

Serial.println(F("Demo complete."));

return;

}

Serial.print(F("Unknown cmd: ")); Serial.println(cmd);

}

void setup() {

Serial.begin(115200);

pinMode(PIN_EN, OUTPUT);

digitalWrite(PIN_EN, LOW); // enable drivers

stepperX.setMaxSpeed(maxSpeed); stepperX.setAcceleration(accel);

stepperY.setMaxSpeed(maxSpeed); stepperY.setAcceleration(accel);

stepperX.setCurrentPosition(0); stepperY.setCurrentPosition(0);

Serial.println(F("CCM Controller: X & Y online"));

Serial.println(F("X: A <deg>, J <±deg>, R, REV <turns>, ZX, CALX <s>"));

Serial.println(F("Y: AY <deg>, JY <±deg>, RY, REVY <turns>, ZY, CALY <s>"));

Serial.println(F("Globals: Z, E/N, SPD <steps/s>, ACC <steps/s^2>, H (X demo)"));

}

void loop() {

// line-based parser

if (Serial.available()) {

String line = Serial.readStringUntil('\n');

handleSerialLine(line);

}

stepperX.run();

stepperY.run();

}

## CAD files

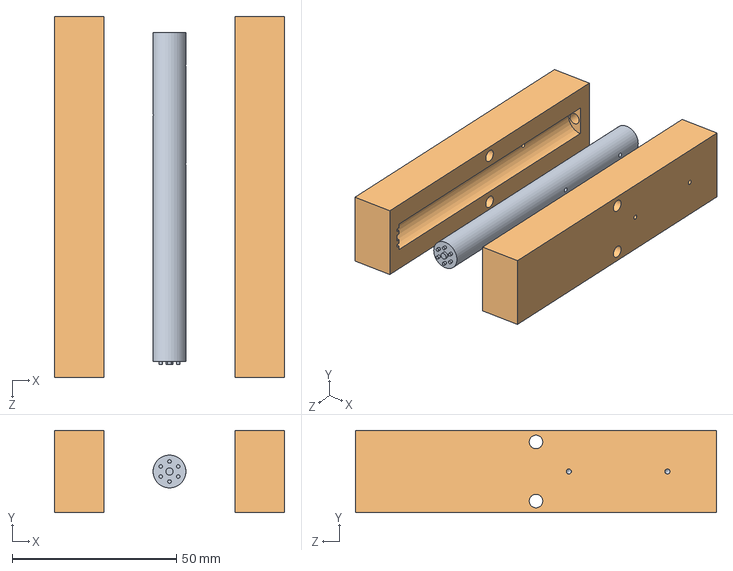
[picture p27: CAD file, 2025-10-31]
Mech_Design/Updated_Design/Updated_Design/Mold_1.SLDASM
70.0 x 25.0 x 110.0 mm
Actuator_1
Part4^Mold_1 x 2

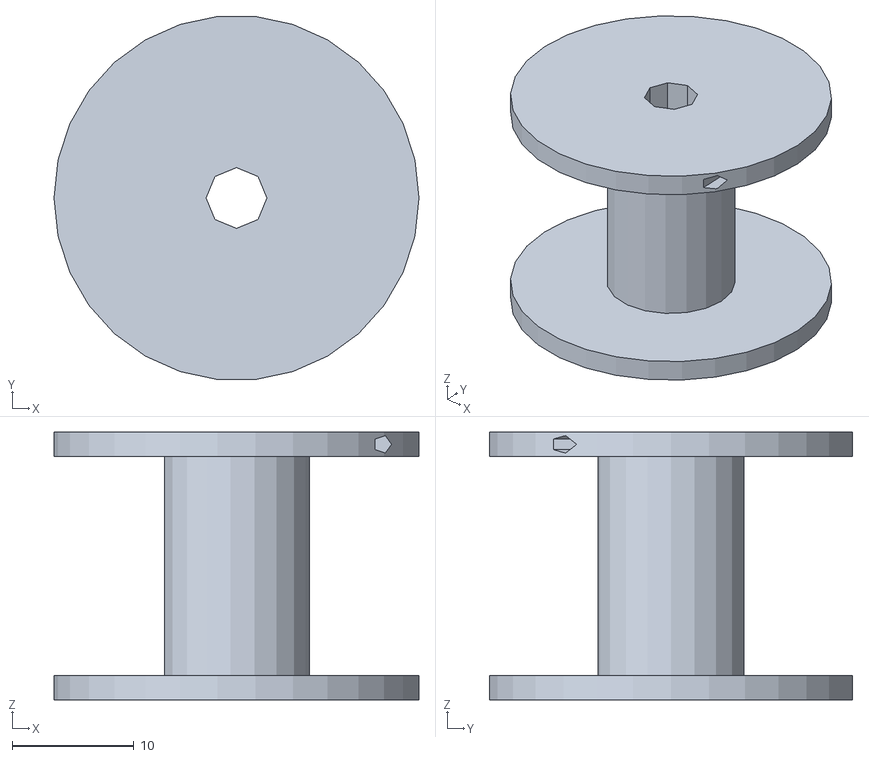
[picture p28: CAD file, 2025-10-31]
Mech_Design/Updated_Design/Spool_Design_Trial_1.stl
30.0 x 29.8 x 22.0

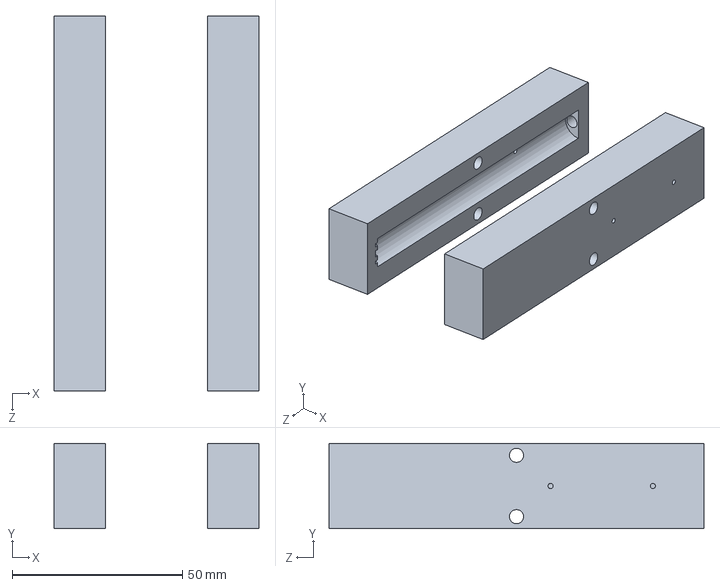
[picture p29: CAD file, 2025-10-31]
Mech_Design/Updated_Design/Updated_Design/Mold_Half_A_1.SLDPRT
60.0 x 25.0 x 110.0 mm

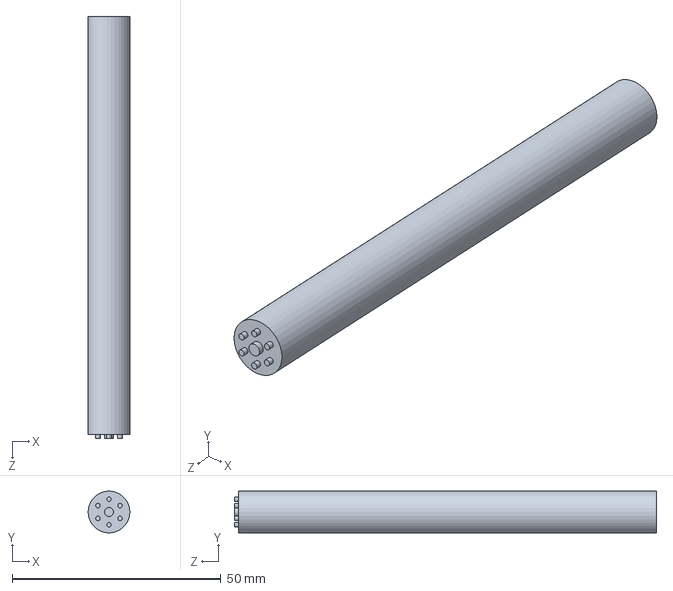
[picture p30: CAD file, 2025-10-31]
Mech_Design/Updated_Design/Updated_Design/Actuator_1.SLDPRT
10.0 x 9.96 x 101.0 mm

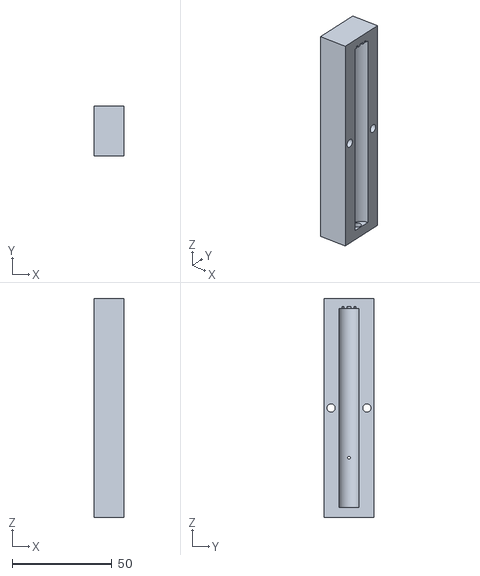
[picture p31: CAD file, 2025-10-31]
Mech_Design/Updated_Design/Updated_Design/Mold_Half_B_1.STL
15.0 x 25.0 x 110.0

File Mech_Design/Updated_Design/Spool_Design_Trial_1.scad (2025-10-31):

// NEMA17 spool with 5mm bore and flange holes
$fn = 100;

bore_dia = 5;
drum_dia = 12;
flange_dia = 30;
drum_length = 20;
flange_thickness = 2;
flange_hole_dia = 1.5;

module spool() {
    difference() {
        union() {
            // Drum
            cylinder(d=drum_dia, h=drum_length);
            // Flange top
            cylinder(d=flange_dia, h=flange_thickness);
            // Flange bottom
            translate([0,0,drum_length])
                cylinder(d=flange_dia, h=flange_thickness);
        }
        // Bore through
        translate([0,0,-1])
            cylinder(d=bore_dia, h=drum_length + 2*flange_thickness + 2);
        // Flange holes (2 opposite)
        for (angle = [0,180]) {
            rotate([0,0,angle])
                translate([flange_dia/2 - 3,0,drum_length + flange_thickness/2])
                    rotate([90,0,0])
                        cylinder(d=flange_hole_dia, h=flange_dia);
        }
    }
}

// Call module
spool();

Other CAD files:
Mech_Design/Updated_Design/Spool_Design_Trial_2.stl
Mech_Design/Updated_Design/Updated_Design/Body1.SLDPRT
Mech_Design/Updated_Design/Updated_Design/MoldHalfA.SLDPRT
Mech_Design/Updated_Design/Updated_Design/Mold_1.STL
Mech_Design/Updated_Design/Updated_Design/Mold_Half_A_1.STL

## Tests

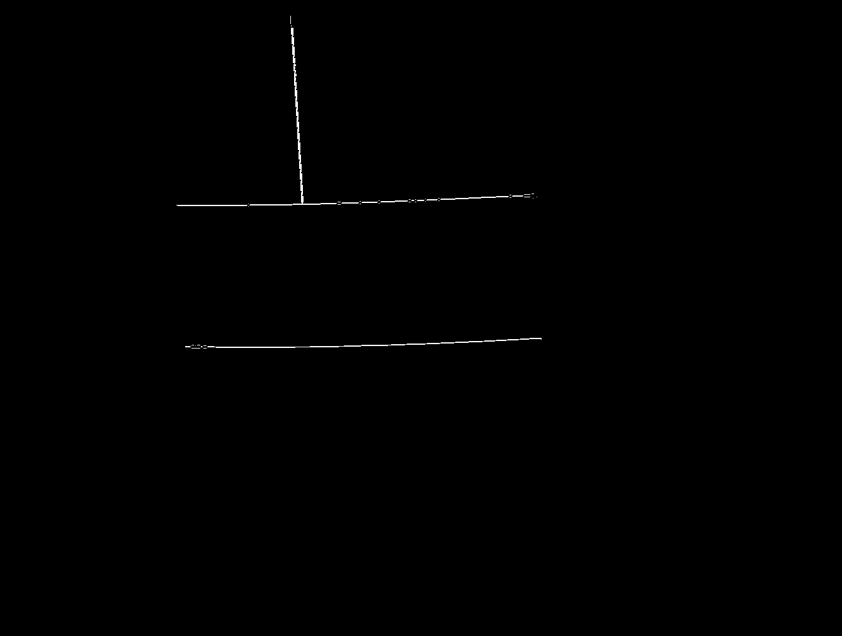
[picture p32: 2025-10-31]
Computer_Vision/Test_Outputs/Static_Image_Trials/Attempts/output_image2.png

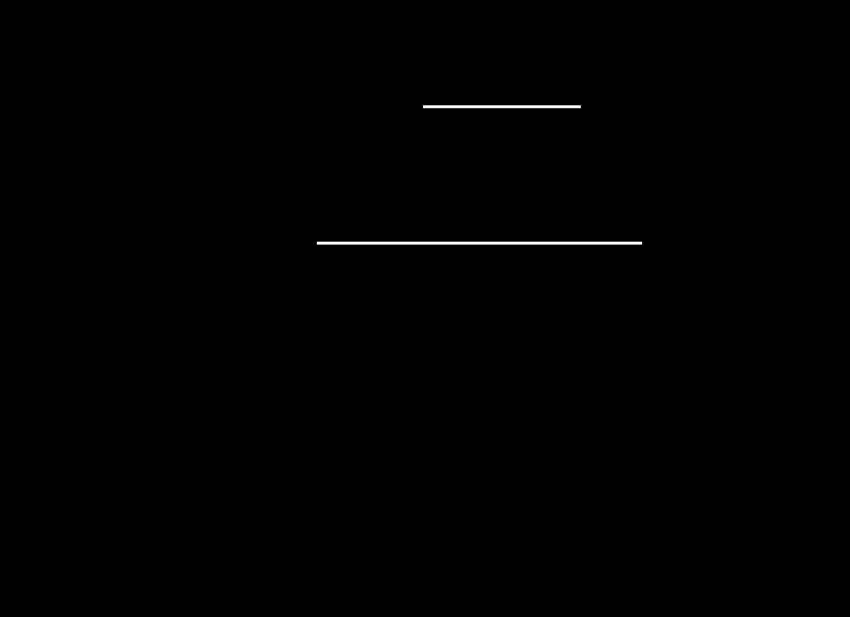
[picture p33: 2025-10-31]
Computer_Vision/Test_Outputs/Static_Image_Trials/Attempts/Processed_Image_1.jpg

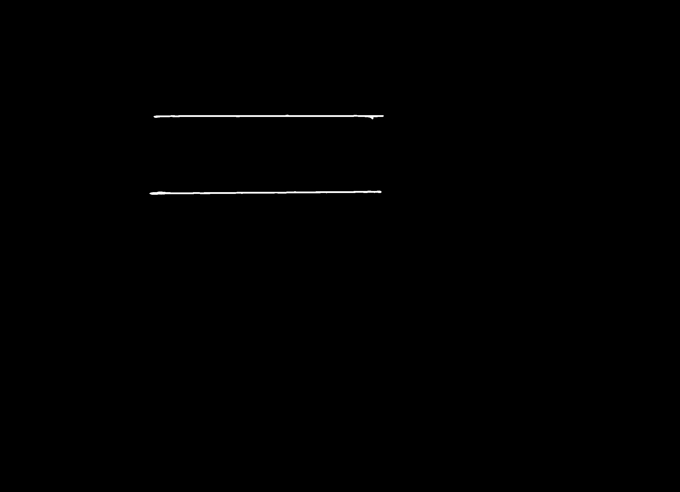
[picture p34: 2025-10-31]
Computer_Vision/Test_Outputs/Static_Image_Trials/Final/image2_processed.jpg

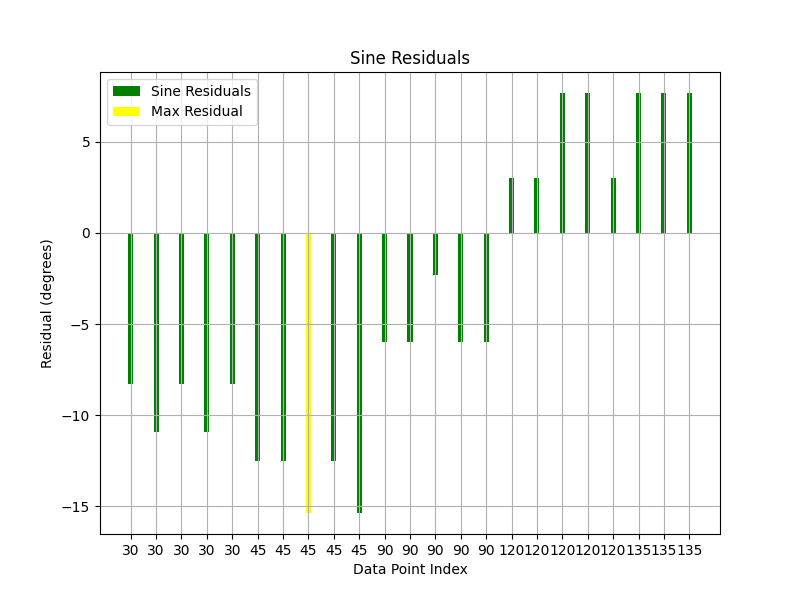
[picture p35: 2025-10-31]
Computer_Vision/Model_Fitting_Evaluation_Plot_3.png

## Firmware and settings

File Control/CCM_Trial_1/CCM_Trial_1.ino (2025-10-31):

#include <AccelStepper.h>

// ===== Pins (Due -> CNC Shield signal rail) =====
const int PIN_STEP = 2;   // D2  -> X.STEP
const int PIN_DIR  = 5;   // D5  -> X.DIR
const int PIN_EN   = 8;   // D8  -> EN (active LOW)

// ===== Microstepping & motor =====
// Set this to your jumper setting (1,2,4,8,16,32...)
const int MICROSTEP = 16;
const int STEPS_PER_REV = 200 * MICROSTEP;   // 1.8° motor

// ===== Geometry (mm) =====
const float R_CABLE_MM = 4.25;               // channel radius from centre
const float R_SPOOL_MM = 6.0;                // spool radius (12 mm dia)
const float CIRC_MM    = 2.0 * 3.1415926535 * R_SPOOL_MM;

// ===== Motion tuning =====
float maxSpeed = 2000.0f;                    // steps/s
const float ACCEL = 2000.0f;                 // steps/s^2
const float JOG_DEG = 5.0f;                  // jog increment

AccelStepper stepper(AccelStepper::DRIVER, PIN_STEP, PIN_DIR);

long zero_steps = 0;     // step offset when you press 'Z'
float target_deg = 0.0;

long angleDegToSteps(float deg) {
  // psi (rad) = deg * pi/180
  float psi = deg * 3.1415926535f / 180.0f;
  // ΔL (mm) = psi * r_cable
  float dLmm = psi * R_CABLE_MM;
  // turns = ΔL / circumference
  float turns = dLmm / CIRC_MM;
  // steps = turns * steps/rev
  long steps = lroundf(turns * (float)STEPS_PER_REV);
  return zero_steps + steps;
}

void setup() {
  Serial.begin(115200);
  pinMode(PIN_EN, OUTPUT);
  digitalWrite(PIN_EN, LOW); // LOW = enable (DRV8825)

  stepper.setMaxSpeed(maxSpeed);
  stepper.setAcceleration(ACCEL);
  stepper.setCurrentPosition(0);

  Serial.println(F("CCM 1-DoF Controller (Due + CNC Shield X)"));
  Serial.println(F("Commands:"));
  Serial.println(F("  Z              -> zero here (after pre-tension)"));
  Serial.println(F("  A <deg>        -> go to bend angle (e.g. A 30)"));
  Serial.println(F("  J + / J -      -> jog +5 / -5 deg"));
  Serial.println(F("  SPD <steps/s>  -> set max speed (e.g. SPD 1200)"));
  Serial.println();
}

void loop() {
  // ---- Serial command parser ----
  if (Serial.available()) {
    char c = Serial.read();

    if (c == 'Z' || c == 'z') {
      zero_steps = stepper.currentPosition();
      target_deg = 0.0f;
      Serial.println(F("Zero set at current position."));
    }
    else if (c == 'A' || c == 'a') {
      float deg = Serial.parseFloat();
      target_deg = deg;
      stepper.moveTo(angleDegToSteps(target_deg));
      Serial.print(F("Target angle -> ")); Serial.print(target_deg); Serial.println(F(" deg"));
    }
    else if (c == 'J' || c == 'j') {
  // Read rest of the line, trim spaces
  String rest = Serial.readStringUntil('\n');
  rest.trim();                   // e.g., "+", "-5", "+ 2.5"
  // Remove any internal spaces
  rest.replace(" ", "");

  float delta = 0.0f;
  if (rest.length() == 0) {
    // default jog if no sign/number provided
    delta = JOG_DEG;
  } else {
    char sign = rest.charAt(0);
    if (sign == '+') {
      if (rest.length() > 1) delta = rest.substring(1).toFloat();
      else delta = JOG_DEG;
    } else if (sign == '-') {
      if (rest.length() > 1) delta = -rest.substring(1).toFloat();
      else delta = -JOG_DEG;
    } else {
      // If user typed a number without sign, treat as +number
      delta = rest.toFloat();
      if (delta == 0) delta = JOG_DEG; // fallback
    }
  }

  target_deg += delta;
  long ts = angleDegToSteps(target_deg);
  stepper.moveTo(ts);
  Serial.print(F("Jog by ")); Serial.print(delta);
  Serial.print(F(" deg -> target ")); Serial.print(target_deg);
  Serial.print(F(" deg, targetSteps=")); Serial.println(ts);
}

    else if (c == 'S' || c == 's') {
      // allow "SPD <value>"
      String rest = Serial.readStringUntil('\n');
      rest.trim();
      if (rest.startsWith("PD")) {
        float spd = rest.substring(2).toFloat();
        if (spd > 0) {
          maxSpeed = spd;
          stepper.setMaxSpeed(maxSpeed);
          Serial.print(F("Max speed = ")); Serial.print(maxSpeed); Serial.println(F(" steps/s"));
        }
      }
    }
   // --- put this BEFORE the single-letter R/E handlers ---
else if (c == 'R' || c == 'r') {
  // Peek ahead to see if user typed REV...
  while (Serial.available() && isspace(Serial.peek())) Serial.read();
  if (Serial.peek() == 'E' || Serial.peek() == 'e') {
    Serial.read(); // eat 'E'
    if (Serial.available()) {
      char v = Serial.read(); // should be 'V' or 'v'
      if (v == 'V' || v == 'v') {
        // parse turns after optional spaces
        String rest = Serial.readStringUntil('\n');
        rest.trim();
        float turns = rest.toFloat();
        long steps = lroundf(turns * (float)STEPS_PER_REV);
        stepper.moveTo(stepper.currentPosition() + steps);
        Serial.print(F("Revolve: ")); Serial.print(turns);
        Serial.print(F(" turns -> ")); Serial.print(steps);
        Serial.println(F(" steps"));
      }
    }
  } else {
    // Plain 'R' = return to zero
    target_deg = 0.0f;
    long ts = angleDegToSteps(0.0f);
    stepper.moveTo(ts);
    Serial.print(F("Return-to-zero: targetSteps=")); Serial.println(ts);
  }
}
else if (c == 'E' || c == 'e') {
  // disable driver
  digitalWrite(PIN_EN, HIGH); // DRV8825: HIGH = disable
  Serial.println(F("Driver disabled (EN=HIGH)."));
}
else if (c == 'N' || c == 'n') {
  // enable driver
  digitalWrite(PIN_EN, LOW);  // DRV8825: LOW = enable
  Serial.println(F("Driver enabled (EN=LOW)."));
}

else if (c == 'A' || c == 'a') { // <-- replace your existing A handler with this:
  float deg = Serial.parseFloat();
  target_deg = deg;
  long ts = angleDegToSteps(target_deg);
  stepper.moveTo(ts);
  Serial.print(F("A cmd: deg=")); Serial.print(target_deg);
  Serial.print(F(", currentPos=")); Serial.print(stepper.currentPosition());
  Serial.print(F(", targetSteps=")); Serial.println(ts);
}

else if (c == 'H' || c == 'h') {
  Serial.println(F("Running 10° back-and-forth demo..."));
  
  float start_deg = target_deg;   // remember where we started
  int cycles = 3;                  // number of back-and-forths
  float move_deg = -10.0;           // bend amount
  
  for (int i = 0; i < cycles; i++) {
    // Move to +10° from zero
    long ts1 = angleDegToSteps(move_deg);
    stepper.moveTo(ts1);
    while (stepper.distanceToGo() != 0) stepper.run();
    delay(500); // pause at bend
    
    // Move back to zero
    long ts0 = angleDegToSteps(0.0);
    stepper.moveTo(ts0);
    while (stepper.distanceToGo() != 0) stepper.run();
    delay(500); // pause at straight
  }
  
  // Return to original position if not zero
  long ts_start = angleDegToSteps(start_deg);
  stepper.moveTo(ts_start);
  while (stepper.distanceToGo() != 0) stepper.run();
  
  Serial.println(F("Demo complete."));
}

    // clear remainder of line
    while (Serial.available()) Serial.read();
  }

  // ---- Run motor toward target ----
  stepper.run();
}
